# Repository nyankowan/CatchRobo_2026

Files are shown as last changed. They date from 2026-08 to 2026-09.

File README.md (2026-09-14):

# CatchRobo_2026
キャチロボ2026で使用する回路データおよび複数マイコンのプログラムを一括管理するリポジトリ.
Team: OBT

## Directory structure
```text
CatchRobo_2026/
├── common/                     ESP32/STM32が共有するプラットフォーム非依存コード
│   ├── arm/
│   │   └── アームの物理パラメータ・ホーミング関連定数・出場チーム(ROBOT_TEAM)
│   │
│   ├── can_protocol/
│   │   └── CAN IDとデータフォーマットの対応定義
│   │
│   └── coordinate/
│       └── 直交座標・極座標変換
│
├── ESP32/
│   └── controller/
│       └── Main Controller(プロコン入力の受信とCANによる各STM32への指令)
│
├── STM32/
│   ├── common/
│   │   └── can/
│   │       └── STM32 HAL CANを使ったCAN送信のラッパー
│   │
│   ├── robomas_controller/
│   │   └── 両アームのr軸・deg軸(Robomaster)制御．ホーミング処理の中枢
│   │
│   ├── lower_arm_servo/
│   │   └── 下アームのハンド(Left/Middle/Right/Expand)とShaftサーボ制御
│   │
│   ├── upper_arm_servo/
│   │   └── 上アームのShaft/Zサーボ制御
│   │
│   └── assemble_servo/
│       └── 整理機構のサーボ制御
│
└── Kicad/
    ├── ESP/
    │   └── ESP Main Controller基板
    ├── STM32F303K8_lower_arm_servo/
    │   └── サーボ制御基板(lower_arm_servo/upper_arm_servo/assemble_servoで共用)
    ├── STM32F446RE_robomas_controller/
    │   └── ロボマス制御基板
    ├── servo/
    │   └── サーボ用補助基板
    └── library/
        └── 共通シンボル・フットプリント
```

各ディレクトリの詳細は，それぞれのREADMEを参照．

| ディレクトリ | README |
| :--- | :--- |
| 共有コード | [common/README.md](common/README.md) |
| CAN通信仕様 | [common/can_protocol/README.md](common/can_protocol/README.md) |
| Main Controller | [ESP32/controller/README.md](ESP32/controller/README.md) |
| STM32全体 | [STM32/README.md](STM32/README.md) |
| 部品リスト | [Kicad/README.md](Kicad/README.md) |

## Hardware

### Actuator
- Robomaster M3508
- DS3225 Servo

### Sensor
- リミットスイッチ(ホーミング用，robomas_controllerに接続)

### Communication
- CAN 1Mbps (ESP32 - STM32, STM32 - Robomaster)

CAN ID・データフォーマットの仕様は [common/can_protocol/README.md](common/can_protocol/README.md) を参照．

## System overview

```mermaid
graph LR
    Pad1[Gamepad1] <-->|Bluetooth| ESP32[ESP32<br>中央制御]
    Pad2[Gamepad2] <-->|Bluetooth| ESP32

    ESP32 --- CAN[CAN BUS]

    CAN --- STM1[STM32 #1<br>robomas_controller]
    CAN --- STM2[STM32 #2<br>lower_arm_servo]
    CAN --- STM3[STM32 #3<br>upper_arm_servo]
    CAN --- STM4[STM32 #4<br>assemble_servo]

    STM1 <-->|CAN| Motor[Robomaster Motor<br>M3508]
    Limit[リミットスイッチ] -->|GPIO| STM1
    STM2 -->|PWM| Servo1[DS3225<br>Left/Middle/Right/Expand/Shaft]
    STM3 -->|PWM| Servo2[DS3225<br>Shaft/Z]
    STM4 -->|PWM| Servo3[DS3225<br>Assemble]
```

## Development environment

### ESP32

#### Hardware
- ESP32-DevKitC-32E

#### Software
- ESP-IDF v5.5.4
- VS Code + ESP-IDF Extension

### STM32

#### Hardware
- STM32 NUCLEO-F303K8
- STM32 NUCLEO-F446RE

#### Software
- STM32CubeMX
- CMake
- VS Code + STM32CubeIDE Extension

### KiCad

#### Software
- KiCad 10.0

## Build

### ESP32

#### Setup
[ESP-IDF環境構築手順（Windows）](https://app.notion.com/p/Windows-36e23f78736380f7b838e187b781a125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)

[ESP-IDF環境構築手順（Linux）](https://app.notion.com/p/L-32323f7873638072bacfeb84175d09c4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)

#### Build
```bash
idf.py build
```
#### Flash
```bash
idf.py flash
```

### STM32

#### Setup
[Qiita: STM32の開発をVSCodeで行う](https://qiita.com/tanutanup/items/d680c92f5168fc3f0182) [@tanutanup(tanutanu p)様](https://qiita.com/tanutanup)

#### Build
各プロジェクト(`STM32/lower_arm_servo`, `STM32/upper_arm_servo`, `STM32/robomas_controller`, `STM32/assemble_servo`)のディレクトリで実行する．
```bash
cmake --preset Release
cmake --build --preset Release
```

## 出場チーム(ROBOT_TEAM)の設定

赤/青チームはフィールドが鏡合わせで，整理機構を左右逆側に取り付けるため，DEG軸のホーミング原点やShaftサーボの回転方向をチームごとに切り替える必要がある．

出場チームは `common/arm/inc/arm.h` の `ROBOT_TEAM`(`ROBOT_TEAM_RED` / `ROBOT_TEAM_BLUE`)としてビルド時の定数で持たせている．緊急停止スイッチでESP32/STM32が再起動しても値を保持する必要があるため，実行時に切り替える方式にはしていない．

**出場チームに応じて`arm.h`のこの値を書き換えた後は，`arm.h`を使う全ファームウェア(ESP32 Main Controller，STM32の`robomas_controller` / `lower_arm_servo` / `upper_arm_servo`)を必ずビルド・書き込みし直すこと．** 値がずれると，DEG軸のホーミングで検出するリミットスイッチと回転方向が基板間で食い違い，可動域の反対側の固定端に衝突する恐れがある．

詳細は [STM32/robomas_controller/README.md](STM32/robomas_controller/README.md) を参照．

## CI

`.github/workflows/` でpush/pull request時に全ファームウェアのビルドを確認している．

| Workflow | 内容 |
| :--- | :--- |
| `esp32-build.yml` | `ESP32/controller` をESP-IDF v5.5.4でビルド |
| `stm32-build.yml` | STM32の4プロジェクトを`cmake --preset Release`でビルド |

ESP-IDFのバージョンとSTM32のツールチェーンは，上記「Development environment」およびDev Containerの設定と揃えること．

## Dev Container (Docker)

ESP-IDF拡張とSTM32系拡張は同じVS Codeウィンドウで有効になっていると干渉するため，用途別にDev Container(Docker)を分けている．必要な拡張機能だけがコンテナ内にインストールされるので，都度手動で拡張をオン/オフする必要がない．

| フォルダを開く | 使うコンテナ | 有効になる拡張 |
| :--- | :--- | :--- |
| `ESP32/controller` | `ESP32/controller/.devcontainer` | ESP-IDF |
| `STM32` | `STM32/.devcontainer` | clangd, CMake Tools, Cortex-Debug |

使い方: 対象のフォルダ(リポジトリ全体ではなく上表のフォルダ)を`File > Open Folder...`で開き，コマンドパレットから`Dev Containers: Reopen in Container`を実行する．どちらのコンテナも各プロジェクトが参照する`common/`(リポジトリ直下)を含むリポジトリ全体をマウントしたうえで，開いたフォルダをエディタ上のワークスペースフォルダとして表示する．

`STM32/.devcontainer`は`lower_arm_servo`/`upper_arm_servo`/`robomas_controller`/`assemble_servo`の4プロジェクト共通で，どのプロジェクトも同じコンテナ内でビルドできる(各プロジェクトのディレクトリに`cd`して上記の`cmake --preset`コマンドを実行)．

`ESP32/controller/.devcontainer`はコンテナ作成時に`components/procon`が依存するBluepad32/BTstack(`~/.espressif/bluepad32`)を自動で取得する(`esp32-build.yml`と同じ手順)．取得結果はDockerボリュームにキャッシュされるため，コンテナを再作成しても毎回cloneし直すことはない．

ST-Link/シリアルポート経由でのフラッシュ・デバッグにはUSBデバイスをコンテナに渡す必要があり，Linuxホスト以外(Windows/macOS)では別途パススルー設定が必要な場合がある．

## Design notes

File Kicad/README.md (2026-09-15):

# Kicad

キャチロボ2026で使用する回路データ(KiCad 10.0)と，その部品リスト．

## Directory structure

```text
Kicad/
├── ESP/
│   └── ESP Main Controller基板(ESP32-DevKitC-32E)
│
├── STM32F303K8_lower_arm_servo/
│   └── サーボ制御基板(lower_arm_servo/upper_arm_servo/assemble_servoで共用)
│
├── STM32F446RE_robomas_controller/
│   └── ロボマス制御基板(NUCLEO-F446RE)
│
├── servo/
│   └── サーボ用補助基板
│
└── library/
    └── 共通シンボル・フットプリント
```

各基板に対応するファームウェアは [STM32/README.md](../STM32/README.md) および [ESP32/controller/README.md](../ESP32/controller/README.md) を参照．

## 部品リスト

このディレクトリにあるキャチロボ2026に向けて作った回路データのほかにも，
岡ロボで使われるCANトランシーバー回路も使用している．

### 回路基板実装部品
#### マイコン基板
- lower_arm_servo基板×3（上側アームと整理機構の制御基板に流用）     
以下一つあたりの部品
    - nucleo-f303k8
    - 3φLED×1
    - 470Ω抵抗×1
    - 5ピンソケット×1
    - 6ピンソケット×1
    - 15pin socket×2

- robomas_controller基板×1
    - nucleo-f446re
    - 19*2ピンソケット×2
    - hirose 2pin(DF1EC-2P-2.5DSA(35))×7
    - 5ピンソケット×2
    - 300Ω抵抗×1
    - φ3LED×1

- ESP Main controller基板×1
    - ESP32-DevKitC-32E
    - 19ピンソケット×2
    - 2ピンソケット×2
    - 5ピンソケット×1
    - φ3LED×7
    - 470Ω抵抗×7

#### 電源基板(N先輩制作)
- catchrobo_2026電源回路×1
    - リレー(942H-2C-24DS)×1
    - ヒューズ×3
    - 470μF×3
    - xt30オス×5
    - xt30メス×4
    - φ5LED×3
    - {1200, 330}Ω抵抗×3
- catchrobo_2026分電回路×2
    - 470μF×1
    - φ5LED×1
    - {1200, 330}Ω抵抗×1
    - xt30メス×4
    - xt30オス×1

#### 補助基板
- servo基板×3   
一つあたりの部品
    - 基板取付用XT30オス(XT30PW-M)×1
    - 1kΩ抵抗×1
    - 220Ω抵抗×5
    - φ3LED×1
    - 1000μF(50PX1000MEFC12.5X25)×1
    - 0.1μF(積層セラミックコンデンサー 0.1μF100V X7R 5mmピッチ)
    - 折れ6pin hirose (DF1E-6P-2.5DS(35))×1
    - 3ピンソケット×5（ヘッダでも可）

- canトランシーバ基板ver1.b×2
- canトランシーバ基板ver1.0×1
- canトランシーバ基板ver1.0 終端抵抗なし×3

- 6.6V -> 5V DCDCコンバータ×1
    - xt30オス×1
    - xt30メス×1

### コード類
#### 電源線
- 電源供給用micro-B×3（2m級×2）
- 電源供給用micro-B×1 （もしくは 2pin オスxt30メス×1）
- 電源供給用mini-B×1　（もしくは 2pin オスxt30メス×1）
- ロボマス電源延長用 xt30 オスメス ×4（15cm程度）
- xt30延長ケーブル×∞

#### 信号線
- リミットスイッチ 2pin hirose オス×6（2m級）
- マイコン間canbus接続用2pin hirose オスオス×4（2m級）
- サーボ電源供給用 xt30オスメス×3（2m級）
- ロボマスcan延長用 2pin hirose オスメス×4（15cm程度）
- canトランシーバ接続用6pinオスメスコネクタ×1（1pin NC）

#### その他
- サーボ延長用 3pin オスメス×5

### 非常停止ボタン　動作ランプなど
- プッシュロック・ターンリセットスイッチ×1
- φ20以上緑LED×1(HWシリーズ パイロットライトΦ22(突形 LED))
- 22VLipo×3
    - xt60オス - xt30メス変換ケーブル×1
- 6.6VLipo×1(並列につなぐ場合×2)
    - xt60オス - xt30メス変換ケーブル×1

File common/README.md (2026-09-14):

# common

ESP32(Main Controller)とSTM32(各種Controller)の両方から参照される，プラットフォーム非依存のC言語共有コード．

CANの通信内容や座標変換など，複数のマイコンで同じ実装・同じ値を使う必要があるものをここに置く．
片方のマイコンでしか使わないコードはここに置かず，それぞれのプロジェクト内に置くこと．

## Directory structure

```text
common/
├── arm/
│   └── アームの物理パラメータ・ホーミング関連定数・出場チーム(ROBOT_TEAM)
│
├── can_protocol/
│   └── CAN IDとデータフォーマットの対応定義
│
└── coordinate/
    └── 直交座標(x, y) ⇔ 極座標(r, θ) の変換
```

## arm

`common/arm/inc/arm.h`

両アーム(Upper/Lower)に共通する物理パラメータと，ホーミング処理に関する定数をまとめる．

- 可動域: `*_ARM_R_RANGE`, `*_ARM_R_MIN`, `*_ARM_DEG_RANGE`, `*_ARM_DEG_MIN`
- 上アームZ軸: `UPPER_ARM_Z_MIN`, `UPPER_ARM_Z_RANGE`, `UPPER_ARM_Z_SERVO_GEAR_DIAMETER`
- 機構の諸元: `R_ROBOMAS_DIAMETER`(R軸ロボマスのギア直径), `POLAR_RATIO`(アーム軸/モーター軸の直径比)
- 出場チーム: `ROBOT_TEAM`(`ROBOT_TEAM_RED`/`ROBOT_TEAM_BLUE`)
- DEG軸のホーミング原点: `LOWER_ARM_DEG_HOME_DEG`, `UPPER_ARM_DEG_HOME_DEG`(`ROBOT_TEAM`で可動域の下限/上限どちらの端になるか変わる)
- 原点座標: `LOWER_ARM_HOME_COORDINATE`, `UPPER_ARM_HOME_COORDINATE`(同じく`ROBOT_TEAM`依存)
- ホーミングのタイムアウト・速度: `HOMING_*_ARM_TIMEOUT_MS`, `HOMING_TIMEOUT_MARGIN_RATE`, `HOMING_*_DEG_RPM`, `HOMING_*_R_RPM`(RPMはタイムアウトと可動域から自動計算される)

STM32(`robomas_controller` / `lower_arm_servo` / `upper_arm_servo`)とESP32(`arm_command.c`)が，同じ可動域・同じタイムアウト値・同じ`ROBOT_TEAM`を参照するために存在する(`assemble_servo`は`arm`を使わない)．
どれか一つだけ値を変えると，可動域チェックやタイムアウト判定，DEG軸ホーミングのリミットスイッチ・回転方向がファームウェア間でズレるので注意．特に`ROBOT_TEAM`は出場チームに応じて書き換えた後，これを使う全ファームウェアを必ずビルド・書き込みし直すこと．

## can_protocol

CAN IDとデータフォーマットの仕様．詳細は [can_protocol/README.md](can_protocol/README.md) を参照．

## coordinate

`common/coordinate/inc/coordinate.h`

```c
typedef struct { double x; double y; } direct_t; // 直交座標
typedef struct { double r; double theta; } polar_t; // 極座標 (theta: rad, 0〜2π)

polar_t to_polar(direct_t d);
```

両アームは物理的には「アームの伸び(r)」と「アームの偏角(θ)」で制御されるが，ジョイスティック入力やCAN通信上は直交座標(x, y)で扱う方が扱いやすいため，この変換関数を共有している．

## ビルドについて

各ディレクトリはそれぞれ独立したCMakeライブラリ(STM32側)／ESP-IDFコンポーネント(ESP32側)として構成されており，`add_subdirectory` または `EXTRA_COMPONENT_DIRS` 経由で各プロジェクトからリンクされる．
具体的なリンク方法は [STM32/README.md](../STM32/README.md) を参照．

| ディレクトリ | STM32でのリンク先ライブラリ名 | リンクするプロジェクト |
| :--- | :--- | :--- |
| `arm/` | `arm` | `robomas_controller`, `lower_arm_servo`, `upper_arm_servo` |
| `can_protocol/` | `can_protocol` | STM32全4プロジェクト |
| `coordinate/` | `coordinate` | `robomas_controller`, `lower_arm_servo`, `upper_arm_servo` |

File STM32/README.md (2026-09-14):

# STM32

キャチロボ2026で使用する4台のSTM32(Nucleo)のプログラムをまとめたディレクトリ．
それぞれSTM32CubeMXで生成された独立したCMakeプロジェクトであり，共通してMain Controller(ESP32)とCANで接続される．

## Directory structure

```text
STM32/
├── common/
│   └── STM32プロジェクト間の共通コード(CANラッパー等)．詳細は common/README.md 参照
│
├── robomas_controller/
│   └── 両アームのr軸・deg軸(Robomaster M3508/M2006)の制御．ホーミング処理の中枢
│
├── lower_arm_servo/
│   └── 下アームのハンド(Left/Middle/Right/Expand)とShaftサーボの制御
│
├── upper_arm_servo/
│   └── 上アームのShaft/Zサーボの制御
│
└── assemble_servo/
    └── 整理機構(Assemble)のサーボ角度制御
```

各プロジェクトの詳細は，それぞれのディレクトリ内のREADME.mdを参照．

| プロジェクト | Nucleo | 基板 | README |
| :--- | :--- | :--- | :--- |
| `robomas_controller` | NUCLEO-F446RE | `Kicad/STM32F446RE_robomas_controller` | [robomas_controller/README.md](robomas_controller/README.md) |
| `lower_arm_servo` | NUCLEO-F303K8 | `Kicad/STM32F303K8_lower_arm_servo` | [lower_arm_servo/README.md](lower_arm_servo/README.md) |
| `upper_arm_servo` | NUCLEO-F303K8 | `Kicad/STM32F303K8_lower_arm_servo`(流用) | [upper_arm_servo/README.md](upper_arm_servo/README.md) |
| `assemble_servo` | NUCLEO-F303K8 | `Kicad/STM32F303K8_lower_arm_servo`(流用) | [assemble_servo/README.md](assemble_servo/README.md) |

CAN ID・データフォーマットの仕様は [common/can_protocol/README.md](../common/can_protocol/README.md) を参照．

## ビルド

各プロジェクトのディレクトリで以下を実行する．

```bash
cmake --preset Release
cmake --build --preset Release
```

4プロジェクト共通のDev Container(`STM32/.devcontainer`)を用意しており，どのプロジェクトも同じコンテナ内でビルドできる(詳細は[リポジトリ直下のREADME.md](../README.md)を参照)．

## 共通ライブラリのリンク方法

STM32/common (CANラッパー) と，ESP32とも共有する common/ (CAN ID定義・座標変換) を，各プロジェクトの `CMakeLists.txt` から以下のようにリンクする．

### 各プロジェクトのCMakeLists.txt
```CMake
# STM32共通CAN
add_subdirectory(
    "${CMAKE_CURRENT_LIST_DIR}/../common/can"
    "${CMAKE_BINARY_DIR}/stm_can"
)

# ESP32 / STM32共通 CAN protocol
add_subdirectory(
    "${CMAKE_CURRENT_LIST_DIR}/../../common/can_protocol"
    "${CMAKE_BINARY_DIR}/can_protocol"
)

# ESP32 / STM32共通 座標処理
add_subdirectory(
    "${CMAKE_CURRENT_LIST_DIR}/../../common/coordinate"
    "${CMAKE_BINARY_DIR}/coordinate"
)

target_link_libraries(${CMAKE_PROJECT_NAME}
    stm32cubemx
    # Add user defined libraries
    stm_can
    can_protocol
    coordinate
)
```

`assemble_servo` は座標変換を使わず角度指令をそのままPWMに変換するだけなので，`coordinate` はリンクしていない(`stm_can` と `can_protocol` のみ)．

`robomas_controller` / `lower_arm_servo` / `upper_arm_servo` は，ホーミング原点・可動域・出場チーム(`ROBOT_TEAM`)の定数を使うため，上記に加えて `common/arm` も追加でリンクしている(`assemble_servo` は使わないためリンクしていない)．

```CMake
# ESP32 / STM32共通 アームパラメータ
add_subdirectory(
    "${CMAKE_CURRENT_LIST_DIR}/../../common/arm"
    "${CMAKE_BINARY_DIR}/arm"
)

target_link_libraries(${CMAKE_PROJECT_NAME}
    ...
    arm
)
```

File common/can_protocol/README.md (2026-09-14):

# CAN Communication Protocol

ESP32およびSTM32間で使用するCAN通信プロトコルの仕様を定義する．

## 1. 基本仕様

| 項目 | 仕様 |
| --- | --- |
| CAN | Classical CAN |
| Bitrate | 1 Mbps |
| CAN ID | Standard ID (11 bit) |
| 最大DLC | 8 byte |
| Byte order | Little-endian |
| CAN ID `0x000` | 使用禁止 |

CANの調停仕様により，CAN IDが小さいメッセージほど高い優先度を持つ．

複数byteの整数値はLittle-endianで格納する．

例として `int16_t value = 0x1234` の場合，

| Byte |  Value |
| ---: | -----: |
| 0 | `0x34` |
| 1 | `0x12` |

となる．

---

## 2. CAN ID一覧

|  CAN ID | Name | DLC | Description |
| ---: | --- | --: | --- |
| `0x001` | `EMERGENCY_STOP` | 0 | 緊急停止 |
| `0x005` | `ROBOMAS_CONTROLLER_HEARTBEAT` | 0 | Robomas Controller生存確認 |
| `0x006` | `UPPER_ARM_HEARTBEAT` | 0 | Upper Arm Controller生存確認 |
| `0x007` | `LOWER_ARM_HEARTBEAT` | 0 | Lower Arm Controller生存確認 |
| `0x010` | `UPPER_HOMING_ACK` | 1 | Upper Arm Homing開始確認 |
| `0x011` | `UPPER_HOMING` | 1 | Upper Arm Homing開始要求 |
| `0x015` | `UPPER_HOMING_DONE_ACK` | 1 | Upper Arm Homing完了通知の確認  |
| `0x016` | `UPPER_HOMING_DONE` | 1 | Upper Arm Homing完了通知 |
| `0x020` | `LOWER_HOMING_ACK` | 1 | Lower Arm Homing開始確認 |
| `0x021` | `LOWER_HOMING` | 1 | Lower Arm Homing開始要求 |
| `0x025` | `LOWER_HOMING_DONE_ACK` | 1 | Lower Arm Homing完了通知の確認  |
| `0x026` | `LOWER_HOMING_DONE` | 1 | Lower Arm Homing完了通知 |
| `0x100` | `UPPER_ARM_COMMAND` | 8 | Upper Armへの操作指令 |
| `0x101` | `LOWER_ARM_COMMAND` | 6 | Lower Armへの操作指令 |
| `0x102` | `ASSEMBLE_COMMAND` | 1 | Assemble機構への操作指令 |
| `0x3F0` | `ERROR_CODE` | 1 | エラー通知 |

DLCは `can_protocol_get_dlc()` によりCAN IDから決定する．

未知のCAN IDに対しては `CAN_DLC_INVALID (-1)` を返す．

---

## 3. Heartbeat

Heartbeatは各ControllerからMain Controllerへの生存確認に使用する．

Heartbeatにはデータを含めず，対応するCAN IDのフレームを受信したこと自体を生存通知として扱う．

|  CAN ID | Sender |
| ---: | --- |
| `0x005` | Robomas Controller |
| `0x006` | Upper Arm Controller |
| `0x007` | Lower Arm Controller |

DLCはすべて `0` とする．

Heartbeatの送信周期とTimeout時間は以下とする．

```c
#define HEARTBEAT_MS         300
#define HEARTBEAT_TIMEOUT_MS 1000
```

各Controllerは300 ms周期でHeartbeatを送信する．

Main Controllerが1000 ms以上Heartbeatを受信できなかった場合，そのControllerとの通信が失われたものとして扱う．

通信喪失を検出した場合は，対応するError Codeを用いてエラーとして処理する．

---

## 4. Homing

Upper ArmおよびLower ArmのHomingでは，

* Homing要求
* Homing ACK
* Homing完了通知
* Homing完了ACK

の4種類のメッセージを使用する．
ホーミング処理の中枢を担うのは`robomas_controller`のみで，
サーボ制御基板(`lower_arm_servo` / `upper_arm_servo`)はHOMINGを受け取ったときにサーボを初期位置へ戻すだけであり，
`HOMING_ACK` / `HOMING_DONE` は返さない．
`assemble_servo`はHomingに関与しない．

基本的な通信シーケンスは以下とする．

```text
Main Controller                     Robomas Controller
      |                                   |
      | -------- HOMING ----------------> |
      | <------- HOMING_ACK ------------- |
      |                                   |
      |          Homing処理                |
      |                                   |
      | <------- HOMING_DONE ------------ |
      | -------- HOMING_DONE_ACK -------->|
      |                                   |
```

Upper Armでは以下のCAN IDを使用する．

|  CAN ID | Name | Direction  |
| ---: | --- | --- |
| `0x010` | `UPPER_HOMING_ACK` | Arm → Main |
| `0x011` | `UPPER_HOMING` | Main → Arm |
| `0x015` | `UPPER_HOMING_DONE_ACK` | Main → Arm |
| `0x016` | `UPPER_HOMING_DONE` | Arm → Main |

Lower Armでは以下のCAN IDを使用する．

|  CAN ID | Name | Direction  |
| ---: | --- | --- |
| `0x020` | `LOWER_HOMING_ACK` | Arm → Main |
| `0x021` | `LOWER_HOMING` | Main → Arm |
| `0x025` | `LOWER_HOMING_DONE_ACK` | Main → Arm |
| `0x026` | `LOWER_HOMING_DONE` | Arm → Main |

すべてのHomingメッセージのDLCは `1` とする．

Byte 0にはsequence numberを格納する．

| Byte | Type | Name | Description |
| ---: | --- | --- | --- |
| 0 | `can_sequence_t` (`uint8_t`) | `sequence` | Sequence Number |

ACKには，対応する要求または通知と同じsequence numberを格納する．

例：

```text
UPPER_HOMING          : sequence = 15
UPPER_HOMING_ACK      : sequence = 15
UPPER_HOMING_DONE     : sequence = 15
UPPER_HOMING_DONE_ACK : sequence = 15
```

sequence numberは `0` ～ `255` を循環して使用する．

---

## 5. Upper Arm Command

### CAN ID

```text
0x100
```

### DLC

```text
8
```

### データフォーマット

| Byte | Type | Name | Description |
| ---: | --- | --- | --- |
|  0-1 | `int16_t` | `x` | X方向指令 (mm)  |
|  2-3 | `int16_t` | `y` | Y方向指令 (mm)  |
|  4-5 | `int16_t` | `z` | Z方向指令 (mm)  |
| 6 | `int8_t`  | `shaft_fine` | シャフト角度の微調整量(度) |
| 7 | `uint8_t` (bit 0) | `shaft_rotate` | 1:ハンドの向きを90度回転させる |

すべてLittle-endianで格納する．

```text
Byte 0 : x LSB
Byte 1 : x MSB

Byte 2 : y LSB
Byte 3 : y MSB

Byte 4 : z LSB
Byte 5 : z MSB

Byte 6 : shaft_fine

Byte 7 : shaft_rotate (bit 0のみ使用)
```

`shaft_rotate=1`は常に90度回転が適用されるとは限らない．下のアームの`shaft_rotate`(180度回転)と同様，出場チーム(青/赤)ごとに定まる，サーボの可動域内に収まるアーム偏角の範囲でのみ受信側(STM32/upper_arm_servo)が回転を適用する．

`shaft_fine`はシャフト角度の微調整オフセット(度)で，`shaft_rotate`とは独立に加算される．有効範囲は`-45`～`45`とし，送信側(`ESP32/controller/main/robot/arm_command.c`の`UPPER_ARM_SHAFT_FINE_MAX_DEG` / `LOWER_ARM_SHAFT_FINE_MAX_DEG`)でこの範囲にクランプする．

受信側の実装(座標からShaftサーボ角度への変換，クランプ)の詳細は[STM32/upper_arm_servo/README.md](../../STM32/upper_arm_servo/README.md)を参照．

C言語上では `upper_arm_t` として表現する．

```c
typedef struct {
    int16_t x;
    int16_t y;
    int16_t z;
    int8_t shaft_fine;
    uint8_t shaft_rotate : 1;
} upper_arm_t;
```

---

## 6. Lower Arm Command

### CAN ID

```text
0x101
```

### DLC

```text
6
```

### データフォーマット

| Byte | Type | Name | Description |
| ---: | --- | --- | --- |
|  0-1 | `int16_t` | `x` | X方向指令 (mm) |
|  2-3 | `int16_t` | `y` | Y方向指令 (mm) |
| 4 | `uint8_t` | `hand` | Hand操作 |
| 5 | `int8_t`  | `shaft_fine` | シャフト角度の微調整量(度) |

`hand`は各bitを以下のように使用する．left/middle/rightはそれぞれ2bitで，`hand_state_t`(0～2)の状態を表す．

| Bit | Name | Description |
| --: | --- | --- |
| 0-1 | `left` | Left hand (`hand_state_t`) |
| 2-3 | `middle` | Middle hand (`hand_state_t`) |
| 4-5 | `right` | Right hand (`hand_state_t`) |
| 6 | `expand` | Expand |
| 7 | `shaft_rotate` | 1:ハンドの向きを180度回転させる |

`shaft_rotate=1`は常に180度回転が適用されるとは限らない．出場チーム(青/赤)ごとに定まる，サーボの可動域内に収まるアーム偏角の範囲でのみ受信側(STM32/lower_arm_servo)が回転を適用する．詳細は[STM32/lower_arm_servo/README.md](../../STM32/lower_arm_servo/README.md)を参照．

`shaft_fine`はシャフト角度の微調整オフセット(度)で，`shaft_rotate`とは独立に加算される．有効範囲は`-45`～`45`とし，送信側(`ESP32/controller/main/robot/arm_command.c`の`UPPER_ARM_SHAFT_FINE_MAX_DEG` / `LOWER_ARM_SHAFT_FINE_MAX_DEG`)でこの範囲にクランプする．

`hand_state_t`は以下の3状態を取る．

| Value | Name | Description |
| ----: | --- | --- |
| 0 | `HAND_STATE_RELEASE` | ワークをリリースする状態 |
| 1 | `HAND_STATE_HOLD` | ワークを保持する状態 |
| 2 | `HAND_STATE_CATCH` | ワークをキャッチする状態  |

各状態に対応する実際のサーボ角度(パルス幅)はハンドの取り付け向きによって変わるため，プロトコルでは規定せず受信側(`lower_arm_servo`)が決める．具体的な値は[STM32/lower_arm_servo/README.md](../../STM32/lower_arm_servo/README.md)を参照．

例えば(MSBからLSBの順)，

```text
0100 0110
```

の場合，

```text
shaft_rotate = 0
expand       = 1
right        = 00 (HAND_STATE_RELEASE)
middle       = 01 (HAND_STATE_HOLD)
left         = 10 (HAND_STATE_CATCH)
```

となる．

C言語上では `lower_arm_t` として表現する．

```c
typedef enum {
    HAND_STATE_RELEASE = 0,
    HAND_STATE_HOLD    = 1,
    HAND_STATE_CATCH   = 2,
} hand_state_t;

typedef struct {
    int16_t x;
    int16_t y;
    union {
        uint8_t hand;
        struct {
            uint8_t left         : 2;
            uint8_t middle       : 2;
            uint8_t right        : 2;
            uint8_t expand       : 1;
            uint8_t shaft_rotate : 1;
        };
    };
    int8_t shaft_fine;
} lower_arm_t;
```

---

## 7. Assemble Command

### CAN ID

```text
0x102
```

### DLC

```text
1
```

Byte 0をAssemble機構への角度指令として使用する．

| Byte | Type | Name  | Description |
| ---: | --- | ----- | --- |
| 0 | `assemble_deg_t` (`uint8_t`) | `deg` | 角度指令 0～90°  |

有効範囲は `0` ～ `90` とする．この上限は `can_protocol.h` の `ASSEMBLE_DEG_RANGE`(=90) として定義し，受信側でこの値にクランプする．

受信側の実装の詳細は[STM32/assemble_servo/README.md](../../STM32/assemble_servo/README.md)を参照．

Assembleには対応するHeartbeat CAN IDが無いため，Main Controllerによる生存監視(3章)の対象外である．

---

## 8. Emergency Stop

### CAN ID

```text
0x001
```

### DLC

```text
0
```

Emergency StopはCAN通信上で最も高い優先度を持つメッセージとする．

受信したControllerは直ちに安全な状態へ移行する．

Emergency StopはCAN通信自体が失われた場合には受信できないため，Heartbeat Timeoutによる異常検出と併用する．

---

## 9. Error Code

### CAN ID

```text
0x3F0
```

### DLC

```text
1
```

Byte 0にError Codeを格納する．

| Byte | Type | Name | Description |
| ---: | --- | --- | --- |
| 0 | `can_error_t` (`uint8_t`) | `error_code` | Error Code  |

Error Codeは `can_error.h` に定義する．

現在定義されているError Codeは以下の通り．

|  Value | Name | Description |
| -----: | --- | --- |
| `0x01` | `CAN_ERROR_LOWER_R_LOST_CONTROL` | 下アームRロボマスからのフィードバックが途絶えた |
| `0x02` | `CAN_ERROR_LOWER_DEG_LOST_CONTROL`  | 下アームDEGロボマスからのフィードバックが途絶えた |
| `0x03` | `CAN_ERROR_UPPER_R_LOST_CONTROL` | 上アームRロボマスからのフィードバックが途絶えた |
| `0x04` | `CAN_ERROR_UPPER_DEG_LOST_CONTROL`  | 上アームDEGロボマスからのフィードバックが途絶えた |
| `0x10` | `CAN_ERROR_LOWER_HOMING_TIMEOUT` | 下アームのホーミングが規定時間内に完了しなかった |
| `0x11` | `CAN_ERROR_UPPER_HOMING_TIMEOUT` | 上アームのホーミングが規定時間内に完了しなかった |
| `0x20` | `CAN_ERROR_LOWER_HOMING_REJECTED` | 下アームがROBOMAS_ERROR中のためホーミング要求を無視した |
| `0x21` | `CAN_ERROR_UPPER_HOMING_REJECTED` | 上アームがROBOMAS_ERROR中のためホーミング要求を無視した |

新しいError Codeを追加する場合は，既存の値と重複しない値を `can_error.h` に追加する．

---

## 10. C言語でのデータ表現

CANデータは以下のunionで表現する．

```c
typedef union {
    uint8_t raw[CAN_DLC_MAX];

    can_sequence_t homing_sequence;
    can_error_t error_code;
    lower_arm_t lower_arm;
    upper_arm_t upper_arm;
    assemble_deg_t assemble_deg;
} can_data_t;
```

現在ESP32およびSTM32はいずれもLittle-endianであるため，CANデータと構造体のメモリ表現を共用している．

ただし，C構造体にはpaddingが挿入される可能性がある．

例えば `lower_arm_t` のCAN上のデータサイズは6 byteだが，

```c
sizeof(lower_arm_t)
```

が6 byteになることは保証されない．

したがって，CAN送信時のDLCを `sizeof()` から決定してはならない．

必ず，

```c
can_protocol_get_dlc(id)
```

によってCAN IDに対応するDLCを取得する．

各構造体が8 byteに収まること，および `can_data_t` 自体が8 byteであることは，

```c
_Static_assert(sizeof(lower_arm_t) <= CAN_DLC_MAX,
               "lower_arm_t is too large");

_Static_assert(sizeof(upper_arm_t) <= CAN_DLC_MAX,
               "upper_arm_t is too large");

_Static_assert(sizeof(can_data_t) == CAN_DLC_MAX,
               "can_data_t must be exactly 8 bytes");
```

によってコンパイル時に確認する．

---

## 11. CAN ID追加時のルール

新しいCANメッセージを追加する場合，以下を定義する．

1. CAN ID
2. メッセージ名
3. 送信元
4. 送信先
5. DLC
6. 各Byte / Bitの意味
7. データ型
8. 単位
9. 有効範囲
10. 送信周期または送信条件
11. Timeout時の処理

CAN IDを決定する際はメッセージの優先度を考慮すること．

CAN IDが小さいほどCANバス上で高い優先度を持つ．

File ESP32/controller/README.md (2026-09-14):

# ESP32/controller

Main Controller．2台のプロコン(Nintendo Switch用ジョイコン等)をBluetoothで受け取り，CAN通信で各STM32(末端マイコン)に指令を送る．

ビルド・書き込み手順とDev Containerについては[リポジトリ直下のREADME.md](../../README.md)を参照．

## Directory structure

```text
ESP32/controller/
├── .devcontainer/          ESP-IDF拡張だけを有効にしたDev Container
│
├── components/
│   ├── can/
│   │   └── CAN(TWAI)通信のラッパー
│   └── procon/
│       └── Bluetoothプロコン(Nintendo Switchコントローラー等)の接続・入力取得
│
└── main/
    ├── main.c              メインループ．プロコン入力の読み取りとロボット制御の呼び出し
    ├── gpio.h              各種GPIO番号(CAN, ステータスLED)の定義
    ├── led.c/h             ステータスLEDの初期化・点灯制御
    ├── micon_connection.c/h  各STM32のHeartbeat監視(通信生存確認)
    └── robot/
        └── arm_command.c/h   両アームへの座標指令・ホーミングシーケンスの実装
```

## components/can

CAN(TWAI)通信をサポートする．

```c
esp_err_t can_init_and_start(gpio_num_t tx, gpio_num_t rx);
esp_err_t can_tx(can_command_data_t *com);
void can_register_rx_callback(can_id_t id, can_rx_callback_t callback);
```

- `can_init_and_start()` で1MbpsのCAN通信を開始する(STM32側の設定と揃える)．
- `can_tx()` で `can_command_data_t` をtxキューに追加して送信する．
- `can_register_rx_callback()` で，特定のCAN ID(`can_id_t`)を受信した際に呼ばれるコールバックを登録できる．コールバックはCAN rx taskから直接呼ばれるため，重い処理を書かないこと．
- `can_error_handling_task()` が，CANのバスオフを検知すると自動的にリカバーする．

CAN ID・データフォーマットの仕様そのものは [common/can_protocol](../../common/can_protocol/README.md) を参照．このプロジェクトでは仕様を実装するだけで，仕様自体はここでは定義しない．

## components/procon

Bluetooth経由でプロコン(ジョイコン等)を接続し，スティック・ボタンの入力を取得する．Bluepad32/BTstackに依存しており，スタックサイズの注意点など実装上のメモは [components/procon/README.md](components/procon/README.md) を参照．

## main

### micon_connection

`CAN_ID_ROBOMAS_CONTROLLER_HEARTBEAT` / `CAN_ID_UPPER_ARM_HEARTBEAT` / `CAN_ID_LOWER_ARM_HEARTBEAT` の受信状況を監視し，各STM32との通信が生きているかを管理する．

```c
void micon_connection_init();
void micon_connection_update();      // 周期的に呼び，Heartbeatタイムアウトを判定する
bool get_connection(micon_type_t m);  // 対象のマイコンと通信できているか
```

`MICON_TYPE_ROBOMAS_CONTROLLER` / `MICON_TYPE_UPPER_ARM` / `MICON_TYPE_LOWER_ARM` の3種類とも実装済み．`assemble_servo`には対応するHeartbeat CAN IDが無いため監視対象外(詳細は[common/can_protocol/README.md](../../common/can_protocol/README.md)参照)．`micon_connection_update()`は`HEARTBEAT_TIMEOUT_MS`(1000ms)を`pdMS_TO_TICKS()`でtick単位に変換してから経過tick数と比較する(逆にすると桁を間違えるので注意)．

### robot/arm_command

両アーム(Upper/Lower)への座標指令とホーミングシーケンスを実装する．
```c
void lower_arm_move(
    int16_t dx, int16_t dy,
    bool left_pressed, bool middle_pressed, bool right_pressed,
    bool release_all_pressed,
    bool expand_toggle,
    int16_t d_shaft_fine,
    bool shaft_rotate_toggle
);
void upper_arm_move(
    int16_t dx, int16_t dy, int16_t dz,
    int16_t d_shaft_fine,
    bool shaft_rotate_toggle
);

esp_err_t send_lower_arm();
esp_err_t send_upper_arm();
esp_err_t arms_init();
esp_err_t lower_arm_homing();
esp_err_t upper_arm_homing();
void arms_update();

void lower_arm_dump();
void upper_arm_dump();
void arms_dump();
```

- `upper_arm_move()` : 座標の差分入力(dx, dy)を現在座標に加算する．可動域(`common/arm`で定義)の外に出る移動は無視する．Zは(dz)を`UPPER_ARM_Z_MIN`~`UPPER_ARM_Z_MIN + UPPER_ARM_Z_RANGE`にクランプしながら加算する．ハンドの向きは，`d_shaft_fine`(L/Rの押しっぱなしで±`UPPER_ARM_SHAFT_FINE_MAX_DEG`の範囲に収まるよう加減算する微調整量，度)と，`shaft_rotate_toggle`(ZL/ZRボタンのPRESSEDエッジ)で90度回転させる`shaft_rotate`の2段構えで制御する(下記`lower_arm_move()`のシャフト制御と同様，回転量が180度から90度になっている点のみ異なる)．ホーミング中は無視する．
- `lower_arm_move()` : 座標(dx, dy)の扱いは`upper_arm_move()`と同様．Left/Middle/Rightの各ハンドは`left_pressed`/`middle_pressed`/`right_pressed`(ボタンのPRESSEDエッジ)を受け取り，シングルクリックでHAND_STATE_CATCH↔HAND_STATE_HOLDを，ダブルクリック(`DOUBLE_CLICK_WINDOW_MS`=300ms以内の2回目の押下)でHAND_STATE_HOLD↔HAND_STATE_RELEASEをトグルする．3本ともHAND_STATE_HOLDのときに`release_all_pressed`(プラスボタン)を受け取ると3本同時にHAND_STATE_RELEASEへ切り替える(いずれかがHAND_STATE_CATCHのときは切り替わらない)．Expandは，トグル入力(ボタンのPRESSEDエッジ)で切り替える．シャフトの向きは，`d_shaft_fine`(L/Rの押しっぱなしで±`LOWER_ARM_SHAFT_FINE_MAX_DEG`の範囲に収まるよう加減算する微調整量，度)と，`shaft_rotate_toggle`(ZL/ZRボタンのPRESSEDエッジ)で180度回転させる`shaft_rotate`の2段構えで制御する．ホーミング中は座標もハンド・シャフト操作も無視する．
- `send_lower_arm()` / `send_upper_arm()` : 現在座標をCANで送信する．ホーミング中は送信しない．
- `lower_arm_homing()` / `upper_arm_homing()` : ホーミング要求(`HOMING`)をSTM32(robomas_controller)に送信する．
- `arms_update()` : 周期的に呼び，`HOMING_ACK`未受信時の要求再送(`HOMING_REQUEST_RETRY_MS`=100msごと)や，ホーミング全体のタイムアウト判定を行う．
- CAN受信コールバック(`*_homing_ack_notify`, `*_homing_done_notify`, `error_code_notify`) で，STM32側からのACK・完了通知・エラー通知を処理する．`error_code_notify`はタイムアウト系・拒否系のエラーを受け取った時点で，ESP32側の10秒待ちを待たずに即座に`homing_in_progress`を解除する．

ホーミングのシーケンス(ACK・DONE・再送を含む)の詳細は [STM32/robomas_controller/README.md](../../STM32/robomas_controller/README.md) を参照．

出場チーム(`common/arm/inc/arm.h`の`ROBOT_TEAM`)を書き換えた場合は，このファームウェアも必ずビルド・書き込みし直すこと(詳細は[リポジトリ直下のREADME.md](../../README.md)を参照)．

### led / gpio

`gpio.h`で定義された7つのLEDを`main_task`のループ毎に更新する．

| LED (`gpio.h`) | 表示内容 |
| :--- | :--- |
| `CONTROLLER_1_LED_GPIO` / `CONTROLLER_2_LED_GPIO` | 各プロコンが接続されているか |
| `ROBOMAS_CONTROLLER_STATUS_LED_GPIO` | `get_connection(MICON_TYPE_ROBOMAS_CONTROLLER)` |
| `LOWER_ARM_STATUS_LED_GPIO` | `get_connection(MICON_TYPE_LOWER_ARM)` |
| `UPPER_ARM_STATUS_LED_GPIO` | `get_connection(MICON_TYPE_UPPER_ARM)` |
| `CAN_STATUS_LED_GPIO` | `can_is_running()`(CANが`TWAI_STATE_RUNNING`か) |
| `STATUS_LED_GPIO` | `main_task`のループ毎にON/OFFを反転させる生存確認用(約3.8Hzで点滅) |

`can_is_running()`は`components/can`に追加したAPIで，`can_error_handling_task()`内で追跡している現在のTWAI状態を返す．

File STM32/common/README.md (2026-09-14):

# STM32/common

STM32側のプロジェクト(`robomas_controller`, `lower_arm_servo`, `upper_arm_servo`, `assemble_servo`)全てから共通で使われるコード．

ESP32とも共有する [common/](../../common/) (CAN ID定義・座標変換)とは別に，STM32のHALを使うコードはこちらに置く．

## Directory structure

```text
STM32/common/
└── can/
    └── STM32 HAL CANを使ったCAN送信のラッパー
```

## can

`STM32/common/can/inc/stm_can.h`

```c
HAL_StatusTypeDef stm_can_send(
    CAN_HandleTypeDef *hcan,
    const can_command_data_t *com
);
```

`common/can_protocol` で定義された `can_command_data_t` を受け取り，CAN IDから `can_protocol_get_dlc()` でDLCを決定した上で `HAL_CAN_AddTxMessage()` を呼び出す．

DLCが不正(未知のCAN IDなど)な場合は送信せず `HAL_ERROR` を返す．

受信については各プロジェクトの `HAL_CAN_RxFifo0MsgPendingCallback()` 内でそれぞれ実装しており，共通化していない．

各プロジェクトの `CMakeLists.txt` からのリンク方法は [STM32/README.md](../README.md) を参照．

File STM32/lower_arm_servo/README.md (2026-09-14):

# STM32/lower_arm_servo

下アームのハンド(Left/Middle/Right/Expand)とShaftサーボを`CAN_ID_LOWER_ARM_COMMAND`/`CAN_ID_LOWER_HOMING`(`common/can_protocol/README.md`参照)経由で制御する．

```text
                 CAN
ESP32 ──────── PA11/PA12
                   │
              STM32F303K8
                   │
       ┌───────────┴───────────┐
       │                       │
     TIM3                    TIM1
  CH1 CH2 CH3 CH4             CH1
  │    │   │   │               │
Lhand  M   R   EXP            shaft
```
## settings
### Pin

| 用途 | STM32ピン | CubeMX設定 | Nucleo端子 |
| --- | --- | --- | --- |
| Left | PB4 | TIM3_CH1 | D12 |
| Middle  | PB5 | TIM3_CH2 | D11 |
| Right | PB0 | TIM3_CH3 | D3 |
| Expand  | PB1 | TIM3_CH4 | D6 |
| Shaft | PA8 | TIM1_CH1 | D9 |
| CAN RX  | PA11 | CAN_RX | D10 |
| CAN TX  | PA12 | CAN_TX | D2 |
| STATUS_LED|PB3 |GPIO_Output| D13 |

### SYS
```text
System Core
└── SYS
Debug = Serial Wire
```
### Clock
```text
RCC
  HSI = ON

Clock Configuration

HSI = 8 MHz
   ↓
SYSCLK = 8 MHz

AHB  /1 → 8 MHz
APB1 /1 → 8 MHz
APB2 /1 → 8 MHz
```

### TIM
#### TIM1
```text
Prescaler      = 7
Counter Period = 19999
Pulse          = 1500
```
#### TIM3
```text
Prescaler      = 7
Counter Period = 19999
Counter Mode   = Up

CH1 Pulse = 1500
CH2 Pulse = 1500
CH3 Pulse = 1500
CH4 Pulse = 1500
```
### CAN
```text
Prescaler                        1
Time Quanta in Bit Segment 1     6
Time Quanta in Bit Segment 2     1
ReSynchronization Jump Width     1
```
```text
CAN
└── NVIC Settings
CAN RX0 interrupt -> Enable
```

## Code
```C
/* USER CODE BEGIN Private defines */
#define Left_htim htim3
#define Middle_htim htim3
#define Right_htim htim3
#define Expand_htim htim3
#define Shaft_htim htim1

#define Left_TIM_CHANNEL TIM_CHANNEL_1
#define Middle_TIM_CHANNEL TIM_CHANNEL_2
#define Right_TIM_CHANNEL TIM_CHANNEL_3
#define Expand_TIM_CHANNEL TIM_CHANNEL_4
#define Shaft_TIM_CHANNEL TIM_CHANNEL_1
```

```C
/* USER CODE BEGIN PD */
#define SERVO_0   500
#define SERVO_270 2500
// Left/Middle/Rightハンドの中間角度(HAND_STATE_HOLD/HAND_STATE_CATCH)のパルス幅
// SERVO_0(0度)~SERVO_270(270度)を基準に角度から線形補間する
#define SERVO_45  833
#define SERVO_225 2167

#define SERVO_150 1622
#define SERVO_120 1388

// ROBOT_TEAM(出場チーム 青/赤)はcommon/arm/inc/arm.hで定義される(ESP32/STM32の
// 全ファームウェアで共有する値なので，このファイルでは再定義しない)。
```

Left(PB4)とMiddle/Right(PB5/PB0)はサーボの取り付け向きが逆なので，同じ`hand_state_t`でも対応するパルス幅が異なる．`hand_state_to_pulse()`がどのハンドの状態かを見て以下のように振り分ける．

| `hand_state_t` | Left | Middle / Right |
| :--- | :--- | :--- |
| `HAND_STATE_RELEASE` | `SERVO_0` | `SERVO_270` |
| `HAND_STATE_HOLD` | `SERVO_45` | `SERVO_225` |
| `HAND_STATE_CATCH` | `SERVO_150` | `SERVO_120` |

Expandも同様に反転しており，`expand=1`で`SERVO_0`，`expand=0`で`SERVO_270`を出力する．

出場チーム(青/赤)は`common/arm/inc/arm.h`の`ROBOT_TEAM`をコード書き込み時に書き換えて固定する．緊急停止スイッチでESP32/STM32(robomas_controller)が再起動しても状態を保持する必要があるため，実行時にトグルする方式ではなく，ビルド時の定数として持たせている．`robomas_controller`など`arm.h`を使う全ファームウェアで必ず同じ値にすること．

### Shaftの角度計算

270度サーボのうち，Shaftが普段使うのは中央の180度(45~225度)だけである．`shaft_deg_from_arm_deg()`が，アームの可動域(`LOWER_ARM_DEG_MIN`~`LOWER_ARM_DEG_MIN + LOWER_ARM_DEG_RANGE` = 0~180度)の中央(=アームが真上向きの偏角90度)がShaft使用域の中央(135度)に一致するよう，偏角にオフセットを足すだけの単純な線形対応で目標角度を求める．

```C
static double shaft_deg_from_arm_deg(direct_t direct){
  double deg = to_polar(direct).theta / (2 * M_PI) * 360.0;
  // アーム可動域の中央(真上向き)をShaft使用域の中央(135度)に合わせるオフセット
  return deg - (LOWER_ARM_DEG_MIN + LOWER_ARM_DEG_RANGE / 2.0) + 135.0;
}
```

`LOWER_ARM_DEG_MIN`は0度で，かつ`to_polar()`の値域[0,2π)の境界と重ならないため，上アーム([STM32/upper_arm_servo/README.md](../upper_arm_servo/README.md)参照)と違い0度付近のラップ補正は不要．この対応では，赤チームのホーミング原点(`LOWER_ARM_DEG_MIN`=0度)が`SERVO_45`，青チームのホーミング原点(`LOWER_ARM_DEG_MIN + LOWER_ARM_DEG_RANGE`=180度)が`SERVO_225`になる．

`shaft_rotate=1`でハンドの向きを180度反転させると，アーム角によっては回転方向側の残り90度分の余裕を超えて可動域の反対側まで回転しきれないことがあるが，そのたびにサーボを取り替えたりはせず，後述の`clamp_servo_pulse()`でパルス幅を`SERVO_0`~`SERVO_270`にクランプすることで「それ以上は回転しない」ことをそのまま許容する．

整理機構は赤/青チームで左右逆側に取り付けるため，余裕が生まれる回転方向もチームで逆になる．`ROBOT_TEAM`に応じて，青チームは`shaft_theta`に`+M_PI`(高いパルス側の余裕を使う)，赤チームは`-M_PI`(低いパルス側の余裕を使う)を加算する．

```C
/* USER CODE BEGIN Includes */
#include "can_protocol.h"
#include "coordinate.h"
#include "stm_can.h"
#include <math.h>
```

Heartbeat送信の実装は非ブロッキング(`HAL_Delay(HEARTBEAT_MS)`のような待機はしない)．詳細は後述の[Heartbeat](#heartbeat)章を参照．

### PWM Start
```C
/* USER CODE BEGIN 2 */
HAL_TIM_PWM_Start(&htim3, Left_TIM_CHANNEL);
HAL_TIM_PWM_Start(&htim3, Middle_TIM_CHANNEL);
HAL_TIM_PWM_Start(&htim3, Right_TIM_CHANNEL);
HAL_TIM_PWM_Start(&htim3, Expand_TIM_CHANNEL);

HAL_TIM_PWM_Start(&htim1, Shaft_TIM_CHANNEL);
```
### PWM Set
以下はServo1に1.5msのPWMを設定する方法．
```C
__HAL_TIM_SET_COMPARE(
    &htim3,
    TIM_CHANNEL_1,
    1500
);
```

### CAN
```C
/* USER CODE BEGIN PV */
CAN_RxHeaderTypeDef rx_header;
can_data_t rx_data = {0};
```

`CAN_ID_LOWER_ARM_COMMAND`(x/y/Left/Middle/Right/Expand/shaft_rotate/shaft_fine)と`CAN_ID_LOWER_HOMING`を受信し，ハンドとShaftサーボのPWMを更新する．Left/Middle/Rightは`hand_state_t`(`HAND_STATE_RELEASE`/`HAND_STATE_HOLD`/`HAND_STATE_CATCH`)の3状態を取り，`hand_state_to_pulse()`で上表のパルス幅に変換する．Shaftは，`shaft_deg_from_arm_deg()`で求めた角度に対して`shaft_rotate=1`でハンドの向きを180度反転し，さらに`shaft_fine`(度)を微調整オフセットとして加えた上で，`clamp_servo_pulse()`によりパルス幅を`SERVO_0`~`SERVO_270`にクランプする．

`CAN_ID_LOWER_HOMING`受信時は`hand_fold()`でハンドをたたみ，Shaftはホーミング原点(`LOWER_ARM_HOME_COORDINATE`)に対応する向き(`shaft_home_pulse()`)にしておく．

```C
/* USER CODE BEGIN 0 */

/**
* @brief 計算したパルス幅を可動域(SERVO_0~SERVO_270)にクランプする．
*        Shaftはshaft_rotate/shaft_fineの加算で可動域を超えることがあるため，
*        クランプした分だけ回転(または微調整)が適用されないことを許容する。
*/
static uint32_t clamp_servo_pulse(double pulse){
  if(pulse < SERVO_0)return SERVO_0;
  if(pulse > SERVO_270)return SERVO_270;
  return (uint32_t)pulse;
}

/**
* @brief hand_state_t(RELEASE/HOLD/CATCH)を対応するサーボのパルス幅に変換する．
*/
static uint32_t hand_state_to_pulse(hand_state_t *state){
  if(state == NULL)return 0;
  if(state == &lower_arm_left){
    switch(*state){
      case HAND_STATE_HOLD:  return SERVO_45;
      case HAND_STATE_CATCH: return SERVO_150;
      case HAND_STATE_RELEASE:
      default:                return SERVO_0;
    }
  }else{
    switch(*state){
      case HAND_STATE_HOLD:  return SERVO_225;
      case HAND_STATE_CATCH: return SERVO_120;
      case HAND_STATE_RELEASE:
      default:                return SERVO_270;
    }
  }
}

/**
* @brief ホーミング原点(LOWER_ARM_HOME_COORDINATE，common/arm/inc/arm.h参照)に対応する
*        Shaftのパルス幅を計算する．
*/
static uint32_t shaft_home_pulse(){
  direct_t home = LOWER_ARM_HOME_COORDINATE;
  double shaft_theta = shaft_deg_from_arm_deg(home) * M_PI / 180.0;
  double shaft_pulse = shaft_theta * (SERVO_270 - SERVO_0) / (3 * M_PI_2) + SERVO_0;
  return (uint32_t)shaft_pulse;
}

/**
* @brief ハンドをたたむ(Shaftはホーミング原点の向きのままにする)
*/
static void hand_fold(){
    __HAL_TIM_SET_COMPARE(&Left_htim,Left_TIM_CHANNEL,SERVO_0);
    __HAL_TIM_SET_COMPARE(&Middle_htim,Middle_TIM_CHANNEL,SERVO_270);
    __HAL_TIM_SET_COMPARE(&Right_htim,Right_TIM_CHANNEL,SERVO_270);
    __HAL_TIM_SET_COMPARE(&Expand_htim,Expand_TIM_CHANNEL,SERVO_270);
    __HAL_TIM_SET_COMPARE(&Shaft_htim,Shaft_TIM_CHANNEL,shaft_home_pulse());
}

void HAL_CAN_RxFifo0MsgPendingCallback(CAN_HandleTypeDef *hcan){
  if(hcan->Instance != CAN)return;
  if(HAL_CAN_GetRxMessage(hcan,CAN_RX_FIFO0,&rx_header,rx_data.raw) != HAL_OK)return;

  switch (rx_header.StdId) {
  case CAN_ID_LOWER_ARM_COMMAND:
    lower_arm_left   = (hand_state_t)rx_data.lower_arm.left;
    lower_arm_middle = (hand_state_t)rx_data.lower_arm.middle;
    lower_arm_right  = (hand_state_t)rx_data.lower_arm.right;
    lower_arm_expand = rx_data.lower_arm.expand;

    __HAL_TIM_SET_COMPARE(&Left_htim,Left_TIM_CHANNEL,hand_state_to_pulse(&lower_arm_left));
    __HAL_TIM_SET_COMPARE(&Middle_htim,Middle_TIM_CHANNEL,hand_state_to_pulse(&lower_arm_middle));
    __HAL_TIM_SET_COMPARE(&Right_htim,Right_TIM_CHANNEL,hand_state_to_pulse(&lower_arm_right));
    if(rx_data.lower_arm.expand){__HAL_TIM_SET_COMPARE(&Expand_htim,Expand_TIM_CHANNEL,SERVO_0);}else{__HAL_TIM_SET_COMPARE(&Expand_htim,Expand_TIM_CHANNEL,SERVO_270);}

    direct_t direct = {.x = rx_data.lower_arm.x, .y = rx_data.lower_arm.y};
    // アームの偏角を，真上向き(90度)がShaft135度になるようオフセットした角度にする
    // (shaft_deg_from_arm_deg()参照)。
    double shaft_theta = shaft_deg_from_arm_deg(direct) * M_PI / 180.0;
    // shaft_rotate=1のとき，アーム軸の回転によらずハンドの向きを180度回転させる。
    // 270度サーボのうち普段使うのは可動範囲分の180度だけなので，回転方向側の残り90度分の
    // 余裕を超える(=可動範囲の反対側まで回転しきれない)場合は，下のclamp_servo_pulse()で
    // パルス幅がクランプされ，それ以上は回転しない(毎回サーボを取り替える運用はしない)。
    // 整理機構は赤/青チームで左右逆側に取り付けるため(arm.h参照)，余裕が生まれる側(=回転
    // させる方向)もチームで逆になる。青は+M_PI(高いパルス側に余裕)，赤は-M_PI(低いパルス側に
    // 余裕)とする。
#if ROBOT_TEAM == ROBOT_TEAM_BLUE
    if(rx_data.lower_arm.shaft_rotate){shaft_theta += M_PI;}
#else
    if(rx_data.lower_arm.shaft_rotate){shaft_theta -= M_PI;}
#endif
    // シャフト角度の微調整(度)。L/Rの押しっぱなしでESP32側が加減算した値をそのまま加える
    shaft_theta += rx_data.lower_arm.shaft_fine * M_PI / 180.0;
    double shaft_pulse = shaft_theta * (SERVO_270 - SERVO_0) / (3 * M_PI_2) + SERVO_0;
    __HAL_TIM_SET_COMPARE(&Shaft_htim,Shaft_TIM_CHANNEL,clamp_servo_pulse(shaft_pulse));
    break;

  case CAN_ID_LOWER_HOMING:
    lower_arm_left = HAND_STATE_RELEASE;
    lower_arm_middle = HAND_STATE_RELEASE;
    lower_arm_right = HAND_STATE_RELEASE;
    lower_arm_expand = false;

    hand_fold();
    break;

  default:
    break;
  }
}
```
```C
/* USER CODE BEGIN 2 */
HAL_CAN_Start(&hcan);
if (HAL_CAN_ActivateNotification(&hcan,CAN_IT_RX_FIFO0_MSG_PENDING) != HAL_OK) {
  Error_Handler();
}
```

### Heartbeat

mainループ内で`HEARTBEAT_MS`(300ms，`common/can_protocol`で定義)周期ごとに`CAN_ID_LOWER_ARM_HEARTBEAT`を送信する．ESP32側はこれの受信有無でLower Arm Controllerとの通信生存を判定する(詳細は[common/can_protocol/README.md](../../common/can_protocol/README.md)のHeartbeat章参照)．

```C
/* USER CODE BEGIN WHILE */
uint32_t last_heartbeat = HAL_GetTick();
while (1)
{
  status_led_update();

  if(HAL_GetTick() - last_heartbeat > HEARTBEAT_MS){
    last_heartbeat = HAL_GetTick();
    stm_can_send(&hcan, &(can_command_data_t){.id = CAN_ID_LOWER_ARM_HEARTBEAT});
  }
  /* USER CODE END WHILE */
  HAL_Delay(LOOP_MS);
  /* USER CODE BEGIN 3 */
}
```

```C
/* USER CODE BEGIN CAN_Init 2 */
/* can_rx setting */
CAN_FilterTypeDef filter;

filter.FilterBank = 0;
filter.FilterMode = CAN_FILTERMODE_IDMASK;
filter.FilterScale = CAN_FILTERSCALE_32BIT;

/* 受信IDフィルター　全受信 */
filter.FilterIdHigh = 0x0000;
filter.FilterIdLow = 0x0000;
filter.FilterMaskIdHigh = 0x0000;
filter.FilterMaskIdLow = 0x0000;

filter.FilterFIFOAssignment = CAN_RX_FIFO0; //fifo(first-in first-out) = Queue
filter.FilterActivation = ENABLE;

if (HAL_CAN_ConfigFilter(&hcan, &filter) != HAL_OK) {
    Error_Handler();
}
/* can_rx setting */
```

### LED

Status_LEDは，Left/Middle/Right/Expandそれぞれの現在の状態(true=ON)を点滅回数で表示する．Left/Middle/Rightは`hand_state_t`のHAND_STATE_RELEASE以外(HOLD/CATCH)をONとして扱う．CAN受信ハンドラでON/OFFを保持しておき，`status_led_update()`を周期的(mainループ毎)に呼ぶことで非ブロッキングに表示する．

表示順は Left → Middle → Right → Expand で，各chはONなら2回，OFFなら1回の短い点滅で表す(点滅回数を数えればON/OFFが分かる)．周期の始まりは長い点灯(マーカー)で示す．

```text
[長い点灯(マーカー)] [消灯] [Left:1or2回点滅] [消灯] [Middle:1or2回点滅] [消灯] [Right:...] [消灯] [Expand:...] [消灯(長め)] → 最初に戻る
```

| 定数 | 値 | 説明 |
| :--- | ---: | :--- |
| `STATUS_LED_MARKER_MS` | 1000 ms | 周期の始まりを示す長い点灯 |
| `STATUS_LED_BLINK_MS` | 100 ms | 1回分の点滅の点灯時間 |
| `STATUS_LED_INTRA_GAP_MS` | 100 ms | ONの2回点滅の間の消灯時間 |
| `STATUS_LED_CHANNEL_GAP_MS` | 700 ms | ch同士の間，およびマーカー直後の消灯時間 |
| `STATUS_LED_END_PAUSE_MS` | 1200 ms | 4ch分表示し終えてから次のマーカーまでの消灯時間 |

実装は`status_led_state_t`によるステートマシン(`STATUS_LED_STATE_MARKER` → `..._CHANNEL_GAP` → `..._BLINK_ON`/`..._BLINK_GAP`(chごとに1〜2回) → `..._END_PAUSE` → 最初に戻る)．ONかOFFかで点滅回数が変わるため，固定長のフェーズ表ではなくこの状態機械で管理している．

`CAN_ID_LOWER_HOMING`受信時は4chとも状態をOFFにリセットし，`hand_fold()`で実際にサーボもたたんだ位置へ戻す．Shaftサーボは，たたんだ状態にはせずホーミング原点(`LOWER_ARM_HOME_COORDINATE`)に対応する向き(`shaft_home_pulse()`)に戻す(ホーミング開始時点からホーミング完了時と同じ向きにしておくことで，完了時にハンドの向きが変わらないようにするため)．Shaftの状態はStatus_LEDの点滅表示には含まれない．

```C
/* USER CODE BEGIN 2 */
HAL_GPIO_WritePin(
  STATUS_LED_GPIO_Port,
  STATUS_LED_Pin,
  GPIO_PIN_SET
);
```
```C
// 点灯
HAL_GPIO_WritePin(
    STATUS_LED_GPIO_Port,
    STATUS_LED_Pin,
    GPIO_PIN_SET
);

// 消灯
HAL_GPIO_WritePin(
    STATUS_LED_GPIO_Port,
    STATUS_LED_Pin,
    GPIO_PIN_RESET
);

// 反転
HAL_GPIO_TogglePin(
    STATUS_LED_GPIO_Port,
    STATUS_LED_Pin
);
```

### Error_Handler
```C
/* USER CODE BEGIN Error_Handler_Debug */
/* User can add his own implementation to report the HAL error return state */
__disable_irq();
while (1)
{
  HAL_GPIO_TogglePin(
  STATUS_LED_GPIO_Port,
  STATUS_LED_Pin
  );
  HAL_Delay(1000);
}
```

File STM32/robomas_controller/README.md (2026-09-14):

# STM32/robomas_controller

両アームのアーム長(r軸)とアーム偏角(deg軸)をRobomaster(M3508/M2006)により制御する．ホーミング処理の中枢を担う．

## settings
### Pin

| 用途 | STM32ピン | CubeMX設定 |
| :--- | :--- | :--- |
| CAN1 (Main Controllerとの通信) | PA11/PA12 | COMMAND_CAN_RX/TX |
| CAN2 (Robomasterとの通信) | PB12/PB13 | ROBOMAS_CAN_RX/TX |
| Status_LED | PA5 | GPIO_Output |
| Upper Arm R軸 リミットスイッチ | PC2 | GPIO_Input (UPPER_ARM_R_LIMIT) |
| Upper Arm Deg軸 下限リミットスイッチ | PC3 | GPIO_Input (UPPER_ARM_DEG_UNDER_LIMIT) |
| Upper Arm Deg軸 上限リミットスイッチ | PC4 | GPIO_Input (UPPER_ARM_DEG_OVER_LIMIT) |
| Lower Arm R軸 リミットスイッチ | PC5 | GPIO_Input (LOWER_ARM_R_LIMIT) |
| Lower Arm Deg軸 下限リミットスイッチ | PC10 | GPIO_Input (LOWER_ARM_DEG_UNDER_LIMIT) |
| Lower Arm Deg軸 上限リミットスイッチ | PC11 | GPIO_Input (LOWER_ARM_DEG_OVER_LIMIT) |

DEG軸は`ROBOT_TEAM`(下記「DEG軸のホーミング方向とROBOT_TEAM」参照)に応じて`_UNDER_LIMIT`/`_OVER_LIMIT`のどちらか一方をホーミングに使う．R軸は`_R_LIMIT`のみ(チームに依らず固定)．

### CAN

他プロジェクト(NUCLEO-F303K8)と違いNUCLEO-F446REのためCubeMXの設定値が異なるが，ビットレートは同じ1Mbps．

| | CAN1 (Main Controller) | CAN2 (Robomaster) |
| :--- | :--- | :--- |
| Prescaler | 2 | 2 |
| Time Quanta in Bit Segment 1 | 12 | 12 |
| Time Quanta in Bit Segment 2 | 2 | 2 |

## 概要

すべてのロボマスターからフィードバックを正常に受け取ることができてから，    
Main Controllerからホーミング指令を受け取り，ホーミング処理が完了して初めて，Main Controllerから制御可能になる．    
ホーミング処理中はMain Controllerからの指令を無視する． 
ホーミング処理はアームごと(r軸・deg軸の2ロボマス1組)に行う．

CAN上のメッセージフォーマットやCAN IDの詳細は [common/can_protocol/README.md](../../common/can_protocol/README.md) を参照．
このREADMEでは，robomas_controller自身がその仕様をどう実装しているか(状態遷移・タイムアウト・再送)を説明する．

サーボ制御基板(`lower_arm_servo` / `upper_arm_servo`)は`HOMING`を受け取ったときにサーボを初期位置へ戻すだけで，`HOMING_ACK` / `HOMING_DONE` は返さない．

mainループ内では`HEARTBEAT_MS`(300ms)周期で`CAN_ID_ROBOMAS_CONTROLLER_HEARTBEAT`を送信し，Main Controllerとの通信生存を通知する(他のSTM32と共通の仕組み)．

## ROBOMASTER_STATE
```C
typedef enum{
  ROBOMAS_INITIAL,  // 初回起動時状態
  ROBOMAS_HOMING,   // 速度制御によって，リミットスイッチ位置まで回転する
  ROBOMAS_IDLE,     // ホーミング終了による他のホーミングを待機
  ROBOMAS_READY,    // ユーザが制御可能な状態
  ROBOMAS_ERROR,    // ロボマスからのフィードバックが途絶えた異常状態
}robomas_state_t;
```
| Value |  explanation |
| :--- | :--- |
|`ROBOMAS_INITIAL`  | マイコン起動時の初期状態．Main Controllerからのホーミング指令により `ROBOMAS_HOMING` に遷移する．|
|`ROBOMAS_HOMING` | ホーミング処理中の状態．リミットスイッチからの信号で `ROBOMAS_IDLE` に遷移する．規定時間内に遷移しなければタイムアウトし `ROBOMAS_INITIAL` に戻る．|
|`ROBOMAS_IDLE` | ホーミング処理を終了し，もう片方(r軸/deg軸)のホーミング完了待ち．両ロボマスがこの状態になると同時に`ROBOMAS_READY`に遷移する．|
|`ROBOMAS_READY` | Main Controllerからの座標指令をもとに制御を行える状態．ホーミング指令により `ROBOMAS_HOMING` に遷移する．|
|`ROBOMAS_ERROR` | `ROBOMAS_FEEDBACK_TIMEOUT_MS`(100ms)以上ロボマスからのフィードバックを受信できていない状態．トルク出力は強制的に0にする．フィードバックが復帰すると自動的に`ROBOMAS_INITIAL`に戻る(制御を再開するには再度ホーミングが必要)．|

r軸・deg軸は基本的に独立して状態遷移するが，`ROBOMAS_READY`への遷移(ホーミング完了)だけは両方が`ROBOMAS_IDLE`になった瞬間に同時に行われる．

---

## ロボマスターのCAN ID対応

`robomas_receive()`は受信したCAN ID(0x201〜0x204)をそのまま配列indexに変換して`robomas[]`に格納している．

```c
uint8_t robomas_id = rx_header.StdId - 0x201; // 0x201→0, 0x202→1, 0x203→2, 0x204→3
```

このindexと実際のアーム・軸の対応は以下の通り．**ロボマスター(C620等)側のCAN ID設定は，この対応に合わせて配線・設定すること．**

| CAN ID | `robomas[]` index | マクロ名 | 対応する軸 |
| :---: | :---: | :--- | :--- |
| `0x201` (ID1) | `robomas[0]` | `robomas_lower_deg` | 下アーム 偏角(deg) |
| `0x202` (ID2) | `robomas[1]` | `robomas_lower_r` | 下アーム 伸縮(r) |
| `0x203` (ID3) | `robomas[2]` | `robomas_upper_deg` | 上アーム 偏角(deg) |
| `0x204` (ID4) | `robomas[3]` | `robomas_upper_r` | 上アーム 伸縮(r) |

配線側のCAN ID設定とこの対応がずれると，例えば意図したR軸の代わりにDEG軸のエラーが報告される，といった混乱の原因になるので注意．

---

## Homingシーケンス

`common/can_protocol/README.md` に記載の

```text
Main Controller                     Robomas Controller
      |                                   |
      | -------- HOMING ----------------> |
      | <------- HOMING_ACK ------------- |
      |                                   |
      |          Homing処理                |
      |                                   |
      | <------- HOMING_DONE ------------ |
      | -------- HOMING_DONE_ACK -------->|
      |                                   |
```

を，CANフレーム欠落があっても最終的に完了できるよう，双方向に再送を実装している．

### HOMING受信 → HOMING_ACK送信
- `CAN_ID_UPPER_HOMING` / `CAN_ID_LOWER_HOMING` を受信すると，受信したsequence numberを保持し，即座に同じsequence numberで `HOMING_ACK` を返す．
- Main Controller側は `HOMING_ACK` が `HOMING_REQUEST_RETRY_MS`(100ms) 以内に届かなければ同じsequence numberでHOMING要求を再送する(実装は`ESP32/controller/main/robot/arm_command.c`)．
- 該当軸が既に`ROBOMAS_IDLE`(もう片方のホーミング待ち)の場合，sequence numberが今処理中のものと一致すればACK消失による再送とみなしてACKを返し直す．一致しない場合は新規の要求とみなし無視する．
- 該当軸が`ROBOMAS_ERROR`の場合，ホーミングは開始せず，`CAN_ID_ERROR_CODE`(`CAN_ERROR_*_HOMING_REJECTED`)を返す．

### Homing処理
- `HOMING_UPPER_DEG_RPM` / `HOMING_LOWER_DEG_RPM` / `HOMING_UPPER_R_RPM` / `HOMING_LOWER_R_RPM` (`common/arm/inc/arm.h`)で指定される回転数でリミットスイッチ方向へ回転する．
- リミットスイッチ検出で`ROBOMAS_IDLE`に遷移し，その時点のロボマス角度を極座標原点として記録する．r軸は`*_ARM_R_MIN`，deg軸は`LOWER/UPPER_ARM_DEG_HOME_DEG`(`common/arm/inc/arm.h`。チーム・原点にする可動端で変わる。下記参照)を考慮したオフセット付き．
- `HOMING_UPPER_ARM_TIMEOUT_MS` / `HOMING_LOWER_ARM_TIMEOUT_MS`(いずれも10000ms)以内にリミットスイッチを検出できなければ，両軸を`ROBOMAS_INITIAL`に戻し，`CAN_ID_ERROR_CODE`(`CAN_ERROR_*_HOMING_TIMEOUT`)を送信する．リミットスイッチ故障や配線不良で無限に回転し続けることを防ぐための仕組み．
- このタイムアウト通知は，一度のホーミング試行につき`upper/lower_homing_timeout_notified`フラグにより1回だけ送信される．`ROBOMAS_ERROR`(フィードバック途絶)状態の軸は上書きせずそのまま`robomas_update()`に管理を委ねるため，タイムアウト処理と`ROBOMAS_ERROR`検知が互いの状態を打ち消し合って`CAN_ID_ERROR_CODE`を送り続ける(スパムする)ことがない．フラグは新しいホーミング要求を受理した時点でリセットされる．

### DEG軸のホーミング方向とROBOT_TEAM
赤/青チームはフィールドが鏡合わせのため，整理機構を左右逆側に付け替える必要がある(機体自体は鏡像に反転するのではなく，180度回転させて取り付ける)．これに合わせて，上下アームとも「DEG軸(偏角)のどちら側の可動端(リミットスイッチ)をホーミング原点にするか」をチームで切り替える．

- 赤チーム: 可動域下限側(`*_DEG_UNDER_LIMIT`，整理機構は左)を原点にする(従来通り)．
- 青チーム: 可動域上限側(`*_DEG_OVER_LIMIT`，整理機構は右)を原点にする．

`ROBOT_TEAM`(`ROBOT_TEAM_RED`/`ROBOT_TEAM_BLUE`)は`common/arm/inc/arm.h`で定義され，ESP32 Main Controller・`lower_arm_servo`・`upper_arm_servo`とこのファームウェアで共有する．**出場チームに応じて`arm.h`のこの値を書き換えてから，全ファームウェアをビルド・書き込みすること(値がずれると，DEG軸のホーミングで検出するリミットスイッチと回転方向が基板間で食い違い，可動域の反対側の固定端に衝突する恐れがある)．**

このファームウェア内では，`ROBOT_TEAM`に応じて以下を切り替えている:
- `*_DEG_HOMING_LIMIT_ON`: ホーミング完了を検出するリミットスイッチ(`*_DEG_UNDER_LIMIT_ON`/`*_DEG_OVER_LIMIT_ON`)．
- `*_DEG_HOMING_DIRECTION_SIGN`: ホーミング時の回転方向の符号．原点にする側へ実際に向かうよう反転させる(配線・機構で決まる固定値`*_DEG_ROBOMAS_DIRECTION`自体は変えない)．
- `set_robomas_deg_from_coordinate()`内の`polar_deg_unwrapped()`: 偏角が360度(=0度)をまたぐ場合(青チームでの上アーム等)に，`to_polar()`の値域[0,2π)によるラップで原点付近の値が不連続にならないよう正規化する．

R軸(アームの伸縮，並進)は原点にする可動端が変わらないため，チームに依らず固定．

### HOMING_DONE送信 → HOMING_DONE_ACK待ち
- 両軸が`ROBOMAS_IDLE`になった瞬間，`ROBOMAS_READY`に遷移すると同時に，保持していたsequence numberで`HOMING_DONE`を送信する．
- `HOMING_DONE_ACK_RETRY_MS`(200ms)ごとに`HOMING_DONE_ACK`の到着を確認し，届いていなければ`HOMING_DONE`を再送する．最大`HOMING_DONE_ACK_MAX_RETRY`(5回)まで再送し，それでも届かなければ諦める(この場合もアーム自体は`ROBOMAS_READY`のまま動作可能)．

---

## 異常検知とエラー通知 (`CAN_ID_ERROR_CODE`)

以下のタイミングで`CAN_ID_ERROR_CODE`(詳細は`common/can_protocol/README.md`)を送信する．

| タイミング | 送信するError Code |
| :--- | :--- |
| ロボマスからのフィードバックが途絶え`ROBOMAS_ERROR`に遷移した瞬間 | `CAN_ERROR_{LOWER,UPPER}_{R,DEG}_LOST_CONTROL` |
| ホーミングが`HOMING_*_ARM_TIMEOUT_MS`以内に完了しなかった | `CAN_ERROR_{LOWER,UPPER}_HOMING_TIMEOUT` |
| `ROBOMAS_ERROR`中にホーミング要求を受けて無視した | `CAN_ERROR_{LOWER,UPPER}_HOMING_REJECTED` |

いずれも状態遷移の瞬間に1回だけ送信し，同じ状態が続く間は再送しない(CANバスを埋めないため)．

---

## 主要タイミング定数一覧

| 定数 | 値 | 定義箇所 | 説明 |
| :--- | ---: | :--- | :--- |
| `ROBOMAS_FEEDBACK_TIMEOUT_MS` | 100 ms | `robomas_controller/Core/Src/main.c` | この時間フィードバックが無いと`ROBOMAS_ERROR`へ |
| `HOMING_UPPER_ARM_TIMEOUT_MS` / `HOMING_LOWER_ARM_TIMEOUT_MS` | 10000 ms | `common/arm/inc/arm.h` | ホーミング全体のタイムアウト．ESP32側の待ち時間も同じ値を参照する |
| `HOMING_DONE_ACK_RETRY_MS` | 200 ms | `robomas_controller/Core/Src/main.c` | `HOMING_DONE`の再送間隔 |
| `HOMING_DONE_ACK_MAX_RETRY` | 5 回 | `robomas_controller/Core/Src/main.c` | `HOMING_DONE`の最大再送回数 |
| `HOMING_REQUEST_RETRY_MS` | 100 ms | `ESP32/controller/main/robot/arm_command.c` | `HOMING`要求(Main Controller→Arm)の再送間隔 |

`HOMING_UPPER/LOWER_DEG_RPM`・`HOMING_UPPER/LOWER_R_RPM`は，上記タイムアウトに対して`HOMING_TIMEOUT_MARGIN_RATE`分の余裕(既定60%)を持って完了するよう`common/arm/inc/arm.h`で自動計算している．

---

## Status_LED

`status_led_update()`が，lower/upperそれぞれのアームが`ROBOMAS_READY`(r軸・deg軸とも)かどうかをStatus_LEDの点滅回数で表示する．周期的(mainループ毎)に呼び出す非ブロッキングの実装．

| 状態 | 表示 |
| :--- | :--- |
| 両方`READY` | 常時点灯 |
| lowerのみ未`READY` | 1回点滅 |
| upperのみ未`READY` | 2回点滅 |
| 両方とも未`READY` | 3回点滅 |

点滅回数 = (lowerが未READYなら+1) + (upperが未READYなら+2) で算出しており，1回点滅→短い消灯→1回点滅…を`blink_count`回繰り返した後，`STATUS_LED_BLINK_PAUSE_MS`(700ms)の消灯を挟んで最初から繰り返す．

| 定数 | 値 | 説明 |
| :--- | ---: | :--- |
| `STATUS_LED_BLINK_ON_MS` | 150 ms | 1回の点滅の点灯時間 |
| `STATUS_LED_BLINK_OFF_MS` | 150 ms | 点滅同士の間の消灯時間 |
| `STATUS_LED_BLINK_PAUSE_MS` | 700 ms | 1周(blink_count回)表示し終えた後の消灯時間 |

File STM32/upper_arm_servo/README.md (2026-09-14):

# STM32/upper_arm_servo

上アームのShaft(ハンドの向き)とZ(昇降)サーボを`CAN_ID_UPPER_ARM_COMMAND`/`CAN_ID_UPPER_HOMING`(`common/can_protocol/README.md`参照)経由で制御する．

同じ回路基板(NUCLEO-F303K8，`Kicad/STM32F303K8_lower_arm_servo`)を使う[STM32/lower_arm_servo](../lower_arm_servo/README.md)と，ピン・タイマー設定・CAN送受信・Status_LEDの基本パターンは共通．CubeMXの詳細な設定値はそちらのREADMEを参照．

## settings
### Pin

| 用途 | STM32ピン | CubeMX設定 | Nucleo端子 |
| --- | --- | --- | --- |
| Shaft | PA8 | TIM1_CH1 | D9 |
| Z | PB1 | TIM3_CH4 | D6 |
| CAN RX  | PA11 | CAN_RX | D10 |
| CAN TX  | PA12 | CAN_TX | D2 |
| STATUS_LED | PB3  | GPIO_Output | D13 |

### TIM

TIM1(Shaft)/TIM3(Z)とも，PWM 20ms周期．`lower_arm_servo`と同じ`Prescaler=7`, `Counter Period=19999`．

### CAN

Prescaler=1, BS1=6TQ, BS2=1TQ, SJW=1TQ (他のF303K8プロジェクトと共通，1Mbps)．

## Code

```C
/* USER CODE BEGIN Private defines */
#define Shaft_htim htim1
#define Z_htim htim3

#define Shaft_TIM_CHANNEL TIM_CHANNEL_1
#define Z_TIM_CHANNEL TIM_CHANNEL_4
```

```C
/* USER CODE BEGIN PD */
#define SERVO_0   500
#define SERVO_270 2500

#define LOOP_MS 2

// 受信コマンドが可動域外でクランプされた場合は高速点滅に切り替えてエラーを知らせる
#define STATUS_LED_ERROR_BLINK_MS 100
```

## 実装状況

`CAN_ID_UPPER_ARM_COMMAND`を受信し，x/yから求めたアームの偏角をShaftサーボ，zをZサーボのPWMへ反映する．`CAN_ID_UPPER_HOMING`受信時はShaftのみホーミング原点(`UPPER_ARM_HOME_COORDINATE`)の向き(`shaft_home_pulse()`)へ戻す(Zは現在位置を維持する)．ホーミング開始時点からホーミング完了時と同じ向きにしておくことで，完了時にハンドの向きが変わらないようにしている(下アームの`shaft_home_pulse()`と同じ考え方，[STM32/lower_arm_servo/README.md](../lower_arm_servo/README.md)参照)．

Homing処理そのもの(リミットスイッチ検出・ロボマスの制御)は`robomas_controller`が担当し，このファームウェアは`HOMING_ACK`/`HOMING_DONE`を返さない(詳細は[common/can_protocol/README.md](../../common/can_protocol/README.md)の4章)．

### Shaftの角度計算

上のアームはハンドの取り付け側が下のアームと逆(180度回転してついている)ため，偏角の可動域は`UPPER_ARM_DEG_MIN`~`UPPER_ARM_DEG_MIN + UPPER_ARM_DEG_RANGE`(180~360度)になる(`common/arm/inc/arm.h`参照)．

Shaftは可動範囲270度のうち中央の180度(45~225度)だけを通常使用域とし，`shaft_deg_from_arm_deg()`が，アームの可動域の中央(=アームが真下向きの位置)がShaft使用域の中央(135度)に一致するよう，偏角からオフセットを引くだけの単純な線形対応で目標角度を求める．

```C
static double shaft_deg_from_arm_deg(direct_t direct){
  double deg = to_polar(direct).theta / (2 * M_PI) * 360.0;
  if(deg < UPPER_ARM_DEG_MIN) deg += 360.0;
  // アーム可動域の中央(真下向き)をShaft使用域の中央(135度)に合わせるオフセット
  return deg - (UPPER_ARM_DEG_MIN + UPPER_ARM_DEG_RANGE / 2.0) + 135.0;
}
```

`fabs()`等で折り返さない線形対応にすることで，アームの回転方向とShaftの回転方向が常に一致し，かつ計算式自体はチームによらず共通になる．チーム差は`UPPER_ARM_HOME_COORDINATE`(`common/arm/inc/arm.h`)が可動域のどちら側の座標になるかにのみ現れ，赤チームのホーミング原点(`UPPER_ARM_DEG_MIN`=180度)では`SERVO_45`，青チームのホーミング原点(`UPPER_ARM_DEG_MIN + UPPER_ARM_DEG_RANGE`=360度)では`SERVO_225`になる．

360度は`coordinate.h`の`to_polar()`の値域[0,2π)では0度としてラップされるため，偏角が0度付近で不連続にならないよう，`UPPER_ARM_DEG_MIN`未満の値には360度を足してから使う．

`shaft_deg_from_arm_deg()`で求めた角度には，さらに`shaft_rotate`(1のときハンドの向きを90度回転させる)と`shaft_fine`(度単位の微調整オフセット)を加算してからShaftサーボのパルス幅に変換する．下のアーム([STM32/lower_arm_servo/README.md](../lower_arm_servo/README.md)参照)と同じ考え方で，270度サーボのうち通常使うのは可動範囲分の180度だけなので，`shaft_rotate=1`による90度回転が残り90度分の余裕を超える場合は下記のクランプにより「それ以上は回転しない」ことを許容する．余裕が生まれる回転方向は整理機構の取り付け側に応じてチームで逆になるため，`ROBOT_TEAM`に応じて青チームは`+90`度，赤チームは`-90`度を加算する．`shaft_fine`は`shaft_rotate`とは独立に加算し，有効範囲は`-45`～`45`度とする(`ESP32/controller/main/robot/arm_command.c`の`UPPER_ARM_SHAFT_FINE_MAX_DEG`)．

### Zの角度計算

zは`UPPER_ARM_Z_SERVO_GEAR_DIAMETER`(`common/arm/inc/arm.h`)のギアで昇降量(mm)からサーボ角度に換算する．

```C
double z_pulse = rx_data.upper_arm.z * (SERVO_270 - SERVO_0) / (UPPER_ARM_Z_SERVO_GEAR_DIAMETER * 3 * M_PI_4) + SERVO_0;
```

### Status_LED

Shaft/Zとも，計算したパルス幅を`SERVO_0`~`SERVO_270`の範囲にクランプしてから`__HAL_TIM_SET_COMPARE()`する．クランプが発生した(=可動域外のコマンドを受信した，または上記の`shaft_rotate`/`shaft_fine`加算で可動域を超えた)場合はSTATUS_LEDを高速点滅(`STATUS_LED_ERROR_BLINK_MS`=100ms)させてエラーを知らせる．正常時はSTATUS_LEDを点灯させ，動作中であることを示す(いずれも`status_led_update()`をmainループ毎に呼ぶことで非ブロッキングに実現)．

なお，ESP32側(`ESP32/controller/main/robot/arm_command.c`)でも送信前にx/y/zを可動域(`common/arm/inc/arm.h`の`UPPER_ARM_R_RANGE`/`UPPER_ARM_DEG_RANGE`/`UPPER_ARM_Z_RANGE`)にクランプしているため，STM32側のクランプは想定外の入力に対する保険(二重の安全策)という位置づけ．

### Heartbeat

mainループ内で`HEARTBEAT_MS`(300ms，`common/can_protocol`で定義)周期ごとに`CAN_ID_UPPER_ARM_HEARTBEAT`を送信する．ESP32側はこれの受信有無でUpper Arm Controllerとの通信生存を判定する(詳細は[common/can_protocol/README.md](../../common/can_protocol/README.md)のHeartbeat章参照)．

```C
/* USER CODE BEGIN WHILE */
uint32_t last_heartbeat = HAL_GetTick();
while (1)
{
  status_led_update();

  if(HAL_GetTick() - last_heartbeat > HEARTBEAT_MS){
    last_heartbeat = HAL_GetTick();
    stm_can_send(&hcan, &(can_command_data_t){.id = CAN_ID_UPPER_ARM_HEARTBEAT});
  }
  /* USER CODE END WHILE */

  HAL_Delay(LOOP_MS);
  /* USER CODE BEGIN 3 */
}
```

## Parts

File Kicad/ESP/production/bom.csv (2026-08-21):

Designator | Footprint | Quantity | Value | LCSC Part #
D1 | LED_D3.0mm | 1 | CAN_STATUS
D2 | LED_D3.0mm | 1 | LOW_STATUS
D3 | LED_D3.0mm | 1 | UP_STATUS
D4 | LED_D3.0mm | 1 | RBMAS_S
D5 | LED_D3.0mm | 1 | CON_1
D6 | LED_D3.0mm | 1 | CON_2
D7 | LED_D3.0mm | 1 | STATUS
J1 | PinHeader_1x02_P2.54mm_Vertical | 1 | 5V
J2 | PinHeader_1x05_P2.54mm_Vertical | 1 | CAN
J3 | PinHeader_1x02_P2.54mm_Vertical | 1 | 3V3
R1, R2, R3, R4, R5, R6, R7 | R_Axial_DIN0207_L6.3mm_D2.5mm_P7.62mm_Horizontal | 7 | 300R
U1 | ESP32_DevKitC_32E | 1 | ESP32_DevKitC-32E

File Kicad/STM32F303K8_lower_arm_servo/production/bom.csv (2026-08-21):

Designator | Footprint | Quantity | Value | LCSC Part #
D1 | LED_D3.0mm | 1 | LED
J1 | PinHeader_1x06_P2.54mm_Vertical | 1 | Servo
J2 | PinHeader_1x05_P2.54mm_Vertical | 1 | CAN
R1 | R_Axial_DIN0207_L6.3mm_D2.5mm_P7.62mm_Horizontal | 1 | 470R
U1 | NUCLEO-F303K8 | 1 | NUCLEO-F303K8

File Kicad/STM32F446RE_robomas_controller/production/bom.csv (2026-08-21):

Designator | Footprint | Quantity | Value | LCSC Part #
D1 | LED_D3.0mm | 1 | Status_LED
J1 | PinHeader_1x02_P2.54mm_Vertical | 1 | UP_R
J2 | PinHeader_1x02_P2.54mm_Vertical | 1 | UP_DEG-
J3 | PinHeader_1x02_P2.54mm_Vertical | 1 | UP_DEG+
J4 | PinHeader_1x02_P2.54mm_Vertical | 1 | LOW_R
J5 | PinHeader_1x02_P2.54mm_Vertical | 1 | LOW_DEG-
J6 | PinHeader_1x02_P2.54mm_Vertical | 1 | LOW_DEG+
J7 | PinHeader_1x05_P2.54mm_Vertical | 1 | COMMAND_CAN
J8 | PinHeader_1x05_P2.54mm_Vertical | 1 | ROBOMAS_CAN
J9 | PinHeader_1x02_P2.54mm_Vertical | 1 | E5V
R1 | R_Axial_DIN0207_L6.3mm_D2.5mm_P7.62mm_Horizontal | 1 | 300R
U3 | MODULE_NUCLEO-F446RE_CN11_CN12_clearance | 1 | NUCLEO-F446RE

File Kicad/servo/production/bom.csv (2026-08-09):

Designator | Footprint | Quantity | Value | LCSC Part #
C1 | CP_Radial_D12.5mm_P5.00mm | 1 | 1000μF
C2 | C_Disc_D5.0mm_W2.5mm_P5.00mm | 1 | 0.1μF
D1 | LED_D3.0mm | 1 | LED
J1 | PinHeader_1x06_P2.54mm_Vertical | 1 | pwm
J2 | PinHeader_1x03_P2.54mm_Vertical | 1 | servo1
J3 | PinHeader_1x03_P2.54mm_Vertical | 1 | servo2
J4 | PinHeader_1x03_P2.54mm_Vertical | 1 | servo3
J5 | PinHeader_1x03_P2.54mm_Vertical | 1 | servo4
J6 | PinHeader_1x03_P2.54mm_Vertical | 1 | servo5
P1 | AMASS_XT30PW-M_1x02_P2.50mm_Horizontal | 1 | XT30
R1, R2, R3, R4, R5 | R_Axial_DIN0207_L6.3mm_D2.5mm_P7.62mm_Horizontal | 5 | 220Ω
R6 | R_Axial_DIN0207_L6.3mm_D2.5mm_P7.62mm_Horizontal | 1 | 1k

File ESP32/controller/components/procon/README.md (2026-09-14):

# ESP32/controller/components/procon

Bluetooth経由でプロコン(Nintendo Switch用コントローラー等)を接続し，スティック・ボタンの入力を取得するコンポーネント．Bluepad32/BTstackに依存する(Dev Containerでの依存取得については[リポジトリ直下のREADME.md](../../../../README.md)を参照)．

## スタックサイズについて

`my_platform.c`のコールバック群は，`app_main()`タスクで呼ばれるループ処理`btstack_run_loop_execute()`で呼ばれる．そのため，sdkconfigで決めることができる`CONFIG_ESP_MAIN_TASK_STACK_SIZE`は，
Bluetooth接続時などは，スタックが深くなり，デフォルトの3584だと足りなくなることがある．
そのため,`on_device_connected()`などが呼ばれるときのスタックの深さを，
```C
ESP_LOGI("STACK", "main task stack remaining (words): %u", uxTaskGetStackHighWaterMark(NULL));
```
で確認し，適切な大きさを設定すると良い．

もしくは，

```C
void bt_run_loop_task(void *arg){
    btstack_run_loop_execute(); // ここでnever return
}

void app_main(void){
    // ... 既存の初期化処理(arms_init(), can_init_and_start(), 各種xTaskCreateなど)は全部先にやっておく ...

    xTaskCreatePinnedToCore(
        bt_run_loop_task,
        "bt_run_loop",
        8192, // ここで明示的にサイズを指定。CONFIG_ESP_MAIN_TASK_STACK_SIZEとは独立
        NULL,
        1, // app main プライオリティ(ESP_TASK_MAIN_PRIO)はデフォルトでは1
        NULL,
        APP_CPU_NUM
    );

    // app_main()はここでreturnできる
}
```
として，sdkconfigの設定と切り離してコード内で管理できるようにすると良い．
このとき，`app_main()`はreturnすると割り当てられていたスタック領域(`CONFIG_ESP_MAIN_TASK_STACK_SIZE`)をヒープに返却する．

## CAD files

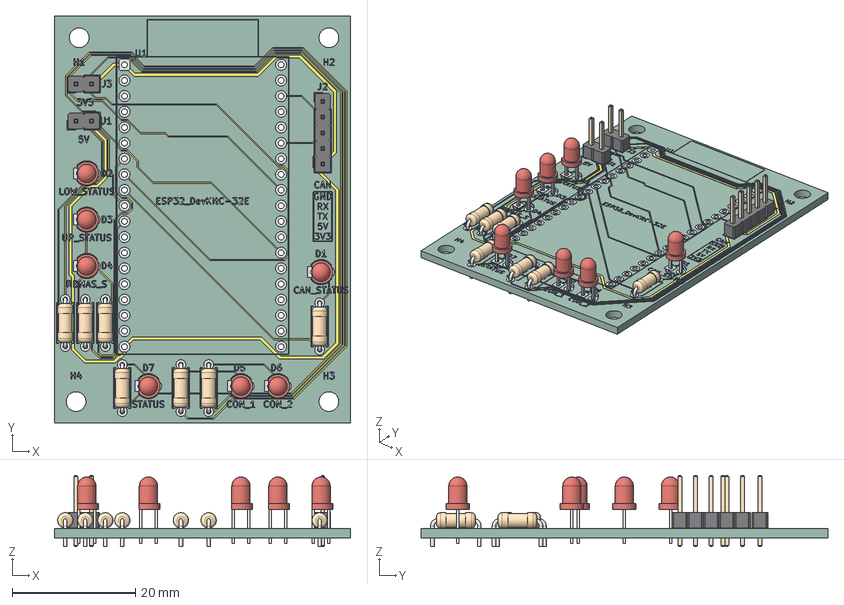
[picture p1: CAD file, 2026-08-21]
Kicad/ESP/.step
48.0 x 65.9 x 11.5 mm
R_Axial_DIN0207_L63mm_D25mm_P762mm_Horizontal x 7
PinHeader_1x02_P254mm_Vertical x 2
LED_D3.0mm x 7
PinHeader_1x05_P254mm_Vertical
ESP_copper
ESP_pad
ESP_silkscreen x 2
ESP_PCB

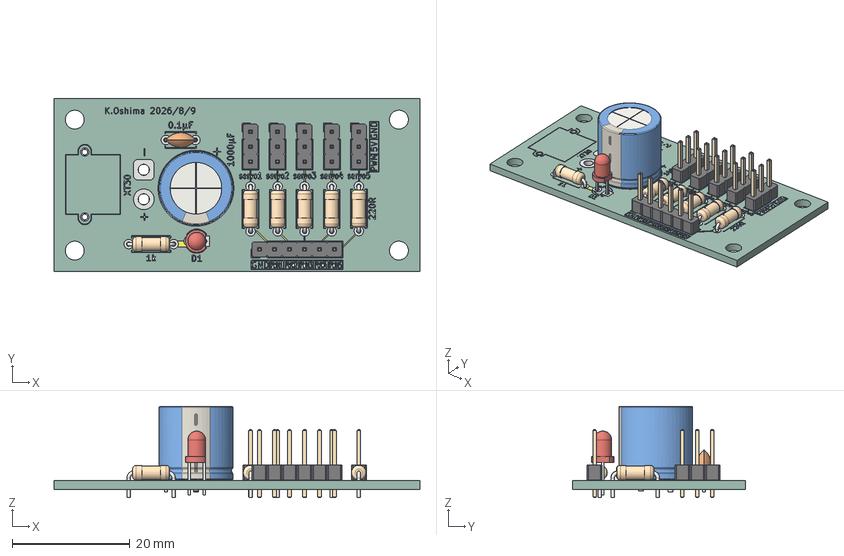
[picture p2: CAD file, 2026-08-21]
Kicad/servo/.step
62.0 x 29.3 x 15.5 mm
R_Axial_DIN0207_L63mm_D25mm_P762mm_Horizontal x 6
PinHeader_1x03_P254mm_Vertical x 5
LED_D3.0mm
PinHeader_1x06_P254mm_Vertical
C_Disc_D50mm_W25mm_P500mm
CP_Radial_D125mm_P500mm
servo_copper
servo_pad
servo_silkscreen x 2
servo_PCB

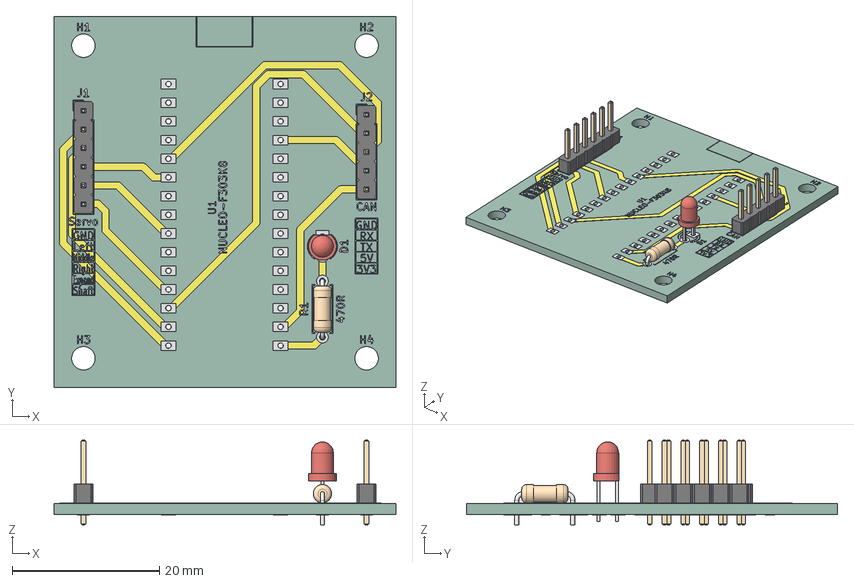
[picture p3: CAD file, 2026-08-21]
Kicad/STM32F303K8_lower_arm_servo/.step
46.5 x 50.5 x 11.5 mm
LED_D3.0mm
PinHeader_1x06_P254mm_Vertical
PinHeader_1x05_P254mm_Vertical
R_Axial_DIN0207_L63mm_D25mm_P762mm_Horizontal
STM32F303K8_lower_arm_servo_copper
STM32F303K8_lower_arm_servo_pad
STM32F303K8_lower_arm_servo_silkscreen x 2
STM32F303K8_lower_arm_servo_PCB

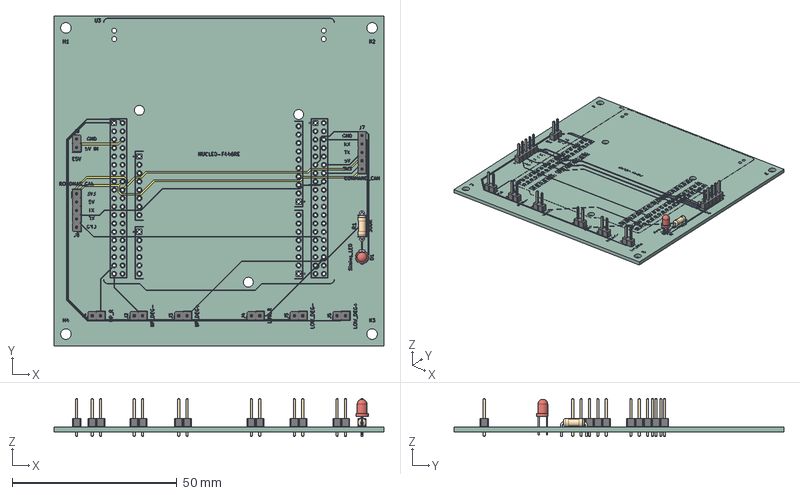
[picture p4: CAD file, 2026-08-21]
Kicad/STM32F446RE_robomas_controller/.step
100.0 x 100.0 x 11.5 mm
PinHeader_1x02_P254mm_Vertical x 7
R_Axial_DIN0207_L63mm_D25mm_P762mm_Horizontal
LED_D3.0mm
PinHeader_1x05_P254mm_Vertical x 2
STM32F446RE_robomas_controller_copper
STM32F446RE_robomas_controller_pad
STM32F446RE_robomas_controller_silkscreen x 2
STM32F446RE_robomas_controller_PCB

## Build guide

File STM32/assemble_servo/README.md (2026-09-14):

# STM32/assemble_servo

整理機構(Assemble)のサーボ角度を`CAN_ID_ASSEMBLE_COMMAND`(`common/can_protocol/README.md`参照)経由で制御する．

同じ回路基板(NUCLEO-F303K8，`Kicad/STM32F303K8_lower_arm_servo`)を使う[STM32/lower_arm_servo](../lower_arm_servo/README.md)と，ピン・タイマー設定・CAN送受信の基本パターンは共通．座標変換もホーミングも使わないため，`common/coordinate`・`common/arm`はリンクしていない．

## settings
### Pin

| 用途 | STM32ピン | CubeMX設定 | Nucleo端子 |
| --- | --- | --- | --- |
| Assemble | PB4 | TIM3_CH1 | D12 |
| CAN RX  | PA11 | CAN_RX | D10 |
| CAN TX  | PA12 | CAN_TX | D2 |
| STATUS_LED | PB3  | GPIO_Output | D13 |

### TIM

TIM3(PWM，20ms周期)．他プロジェクト(lower_arm_servo等)と同じ`Prescaler=7`, `Counter Period=19999`．

### CAN

Prescaler=1, BS1=6TQ, BS2=1TQ, SJW=1TQ (他のF303K8プロジェクトと共通，1Mbps)．

## Code

```C
/* USER CODE BEGIN PD */
#define SERVO_0   500
#define SERVO_270 2500
#define SERVO_DEG_RANGE 270 //サーボの角度(0-270deg)とパルス幅(SERVO_0-SERVO_270)の換算に使う定数

#define STATUS_LED_BLINK_MS 200 //異常時のLED点滅間隔
```

```C
/* USER CODE BEGIN Private defines */
#define ASSEMBLE_htim htim3
#define ASSEMBLE_TIM_CHANNEL TIM_CHANNEL_1
```

### CAN

`CAN_ID_ASSEMBLE_COMMAND`(DLC=1，角度指令0〜90°)を受信すると，機構の可動域(`ASSEMBLE_DEG_RANGE`=90，`common/can_protocol/inc/can_protocol.h`で定義)にクランプした上でサーボPWMに変換して出力する．

ホーミングには関与しないため，`CAN_ID_ASSEMBLE_COMMAND`以外のCAN IDは無視する．

```C
/* USER CODE BEGIN 0 */
void HAL_CAN_RxFifo0MsgPendingCallback(CAN_HandleTypeDef *hcan){
  CAN_RxHeaderTypeDef rx_header;
  can_data_t rx_data = {0};
  if(hcan->Instance != CAN)return;
  if(HAL_CAN_GetRxMessage(hcan,CAN_RX_FIFO0,&rx_header,rx_data.raw) != HAL_OK)return;

  switch (rx_header.StdId) {
  case CAN_ID_ASSEMBLE_COMMAND: {
    assemble_deg_t deg = rx_data.assemble_deg;
    if(deg > ASSEMBLE_DEG_RANGE) deg = ASSEMBLE_DEG_RANGE; //機構の可動域(0-90度)にクランプ
    __HAL_TIM_SET_COMPARE(&ASSEMBLE_htim,ASSEMBLE_TIM_CHANNEL,
      (uint16_t)((double)deg / SERVO_DEG_RANGE * (SERVO_270 - SERVO_0) + SERVO_0));
    break;
  }
  default:
    break;
  }
}
```

Assembleには`common/can_protocol`が定義するHeartbeat CAN IDが無いため，ESP32側の`micon_connection`による生存監視の対象外(詳細は[common/can_protocol/README.md](../../common/can_protocol/README.md)参照)．

### Status_LED

CANのバスオフ／エラーパッシブ／エラーワーニングいずれかを検知したら異常状態としてラッチし，`STATUS_LED_BLINK_MS`(200ms)間隔で点滅させる．正常時は常時点灯．

```C
/* USER CODE BEGIN 3 */
//CANバスエラー(バスオフ/エラーパッシブ/エラーワーニング)を検知したらラッチする
if(__HAL_CAN_GET_FLAG(&hcan, CAN_FLAG_BOF) ||
   __HAL_CAN_GET_FLAG(&hcan, CAN_FLAG_EPV) ||
   __HAL_CAN_GET_FLAG(&hcan, CAN_FLAG_EWG)){
  can_bus_error = 1;
}

if(can_bus_error){
  //異常時: 点滅
  uint32_t now = HAL_GetTick();
  if(now - status_led_last_toggle >= STATUS_LED_BLINK_MS){
    status_led_last_toggle = now;
    HAL_GPIO_TogglePin(STATUS_LED_GPIO_Port, STATUS_LED_Pin);
  }
}else{
  //正常動作中: 点灯
  HAL_GPIO_WritePin(STATUS_LED_GPIO_Port, STATUS_LED_Pin, GPIO_PIN_SET);
}
```

### Error_Handler

初期化失敗などでHALの割り込みが止まり`HAL_GetTick()`が進まなくなった場合に備え，`Error_Handler()`内ではタイマー割り込みに頼らないソフトウェアループでLEDを点滅させる．

```C
/* USER CODE BEGIN Error_Handler_Debug */
__disable_irq();
while (1)
{
  HAL_GPIO_TogglePin(STATUS_LED_GPIO_Port, STATUS_LED_Pin);
  for(volatile uint32_t i = 0; i < 400000; i++){}
}
```

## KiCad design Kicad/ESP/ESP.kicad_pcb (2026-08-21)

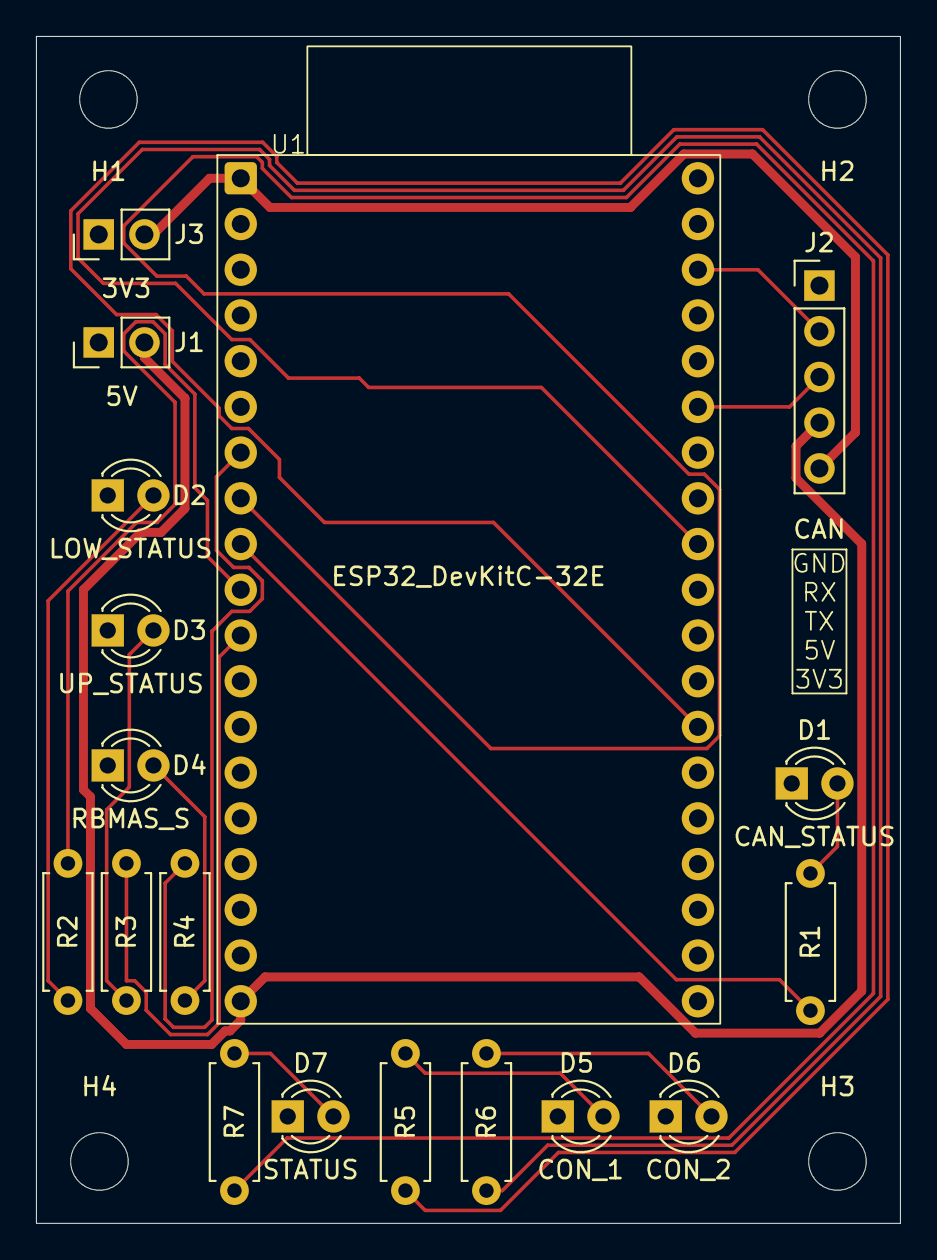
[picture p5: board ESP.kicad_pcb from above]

Board: 2 copper layers, 48.0 x 65.9 mm, 22 parts (0 on the bottom side), 19 nets.

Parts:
D1: CAN_STATUS; LED_D3.0mm
D2: LOW_STATUS; LED_D3.0mm
D3: UP_STATUS; LED_D3.0mm
D4: RBMAS_S; LED_D3.0mm
D5: CON_1; LED_D3.0mm
D6: CON_2; LED_D3.0mm
D7: STATUS; LED_D3.0mm
H1, H2, H3, H4: MountingHole; MountingHole_3.2mm_M3
J1: 5V; PinHeader_1x02_P2.54mm_Vertical
J2: CAN; PinHeader_1x05_P2.54mm_Vertical
J3: 3V3; PinHeader_1x02_P2.54mm_Vertical
R1, R2, R3, R4, R5, R6, R7: 300R; R_Axial_DIN0207_L6.3mm_D2.5mm_P7.62mm_Horizontal
U1: ESP32_DevKitC-32E; ESP32_DevKitC_32E

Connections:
+3.3V: J2.5, J3.2, U1.1 (3V3)
+5V: J1.2, J2.4, U1.19 (5V)
/CAN_RX: J2.2, U1.22 (GPIO22)
/CAN_STATUS_LED_GPIO: R1.1, U1.9 (GPIO25)
/CAN_TX: J2.3, U1.25 (GPIO21)
/CONTROLLER_1_LED_GPIO: R5.1, U1.32 (GPIO4)
/CONTROLLER_2_LED_GPIO: R6.1, U1.28 (GPIO18)
/LOWER_ARM_STATUS_LED_GPIO: R2.1, U1.10 (GPIO26)
/ROBOMAS_CONTROLLER_STATUS_LED_GPIO: R4.1, U1.7 (GPIO32)
/STATUS_LED_GPIO: R7.1, U1.8 (GPIO33)
/UPPER_ARM_STATUS_LED_GPIO: R3.1, U1.11 (GPIO27)
GND: D1.1 (K), D2.1 (K), D3.1 (K), D4.1 (K), D5.1 (K), D6.1 (K), D7.1 (K), J1.1, J2.1, J3.1, U1.14 (GND), U1.20 (GND), U1.26 (GND)
unnamed: D1.2 (A), R1.2
unnamed: D2.2 (A), R2.2
unnamed: D3.2 (A), R3.2
unnamed: D4.2 (A), R4.2
unnamed: D5.2 (A), R5.2
unnamed: D6.2 (A), R6.2
unnamed: D7.2 (A), R7.2

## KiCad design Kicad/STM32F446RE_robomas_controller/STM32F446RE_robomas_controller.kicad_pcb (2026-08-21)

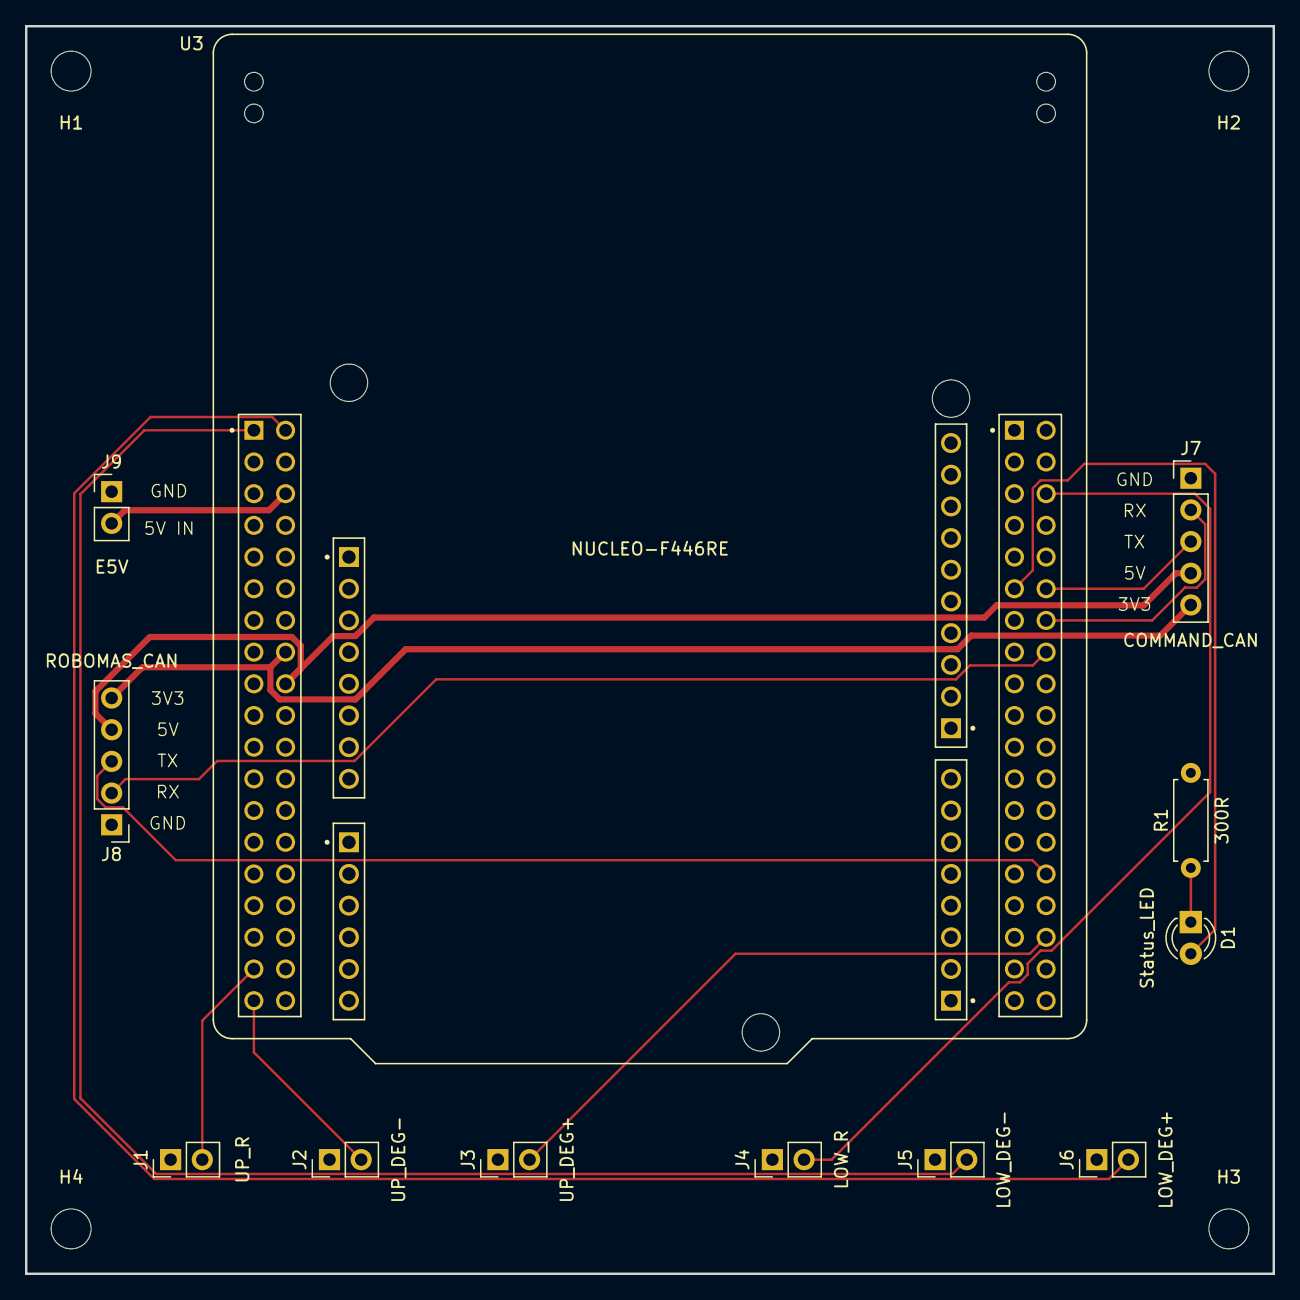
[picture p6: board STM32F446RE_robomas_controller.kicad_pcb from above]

Board: 2 copper layers, 100.0 x 100.0 mm, 16 parts (0 on the bottom side), 16 nets.

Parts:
D1: Status_LED; LED_D3.0mm
H1, H2, H3, H4: MountingHole; MountingHole_3.2mm_M3
J1: UP_R; PinHeader_1x02_P2.54mm_Vertical
J2: UP_DEG-; PinHeader_1x02_P2.54mm_Vertical
J3: UP_DEG+; PinHeader_1x02_P2.54mm_Vertical
J4: LOW_R; PinHeader_1x02_P2.54mm_Vertical
J5: LOW_DEG-; PinHeader_1x02_P2.54mm_Vertical
J6: LOW_DEG+; PinHeader_1x02_P2.54mm_Vertical
J7: COMMAND_CAN; PinHeader_1x05_P2.54mm_Vertical
J8: ROBOMAS_CAN; PinHeader_1x05_P2.54mm_Vertical
J9: E5V; PinHeader_1x02_P2.54mm_Vertical
R1: 300R; R_Axial_DIN0207_L6.3mm_D2.5mm_P7.62mm_Horizontal
U3: NUCLEO-F446RE; MODULE_NUCLEO-F446RE_CN11_CN12_clearance

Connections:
+3.3V: J7.5, J8.5, U3.CN7_16 (CN7_+3V3)
+5V: J7.4, J8.4, U3.CN7_18 (CN7_+5V)
/COMMAND_CAN_RX: J7.2, U3.CN10_14 (PA11)
/COMMAND_CAN_TX: J7.3, U3.CN10_12 (PA12)
/E5V: J9.2, U3.CN7_6 (E5V)
/LOWER_ARM_DEG_OVER_LIMIT: J6.2, U3.CN7_2 (PC11)
/LOWER_ARM_DEG_UNDER_LIMIT: J5.2, U3.CN7_1 (PC10)
/LOWER_ARM_R_LIMIT: J4.2, U3.CN10_6 (PC5)
/ROBOMAS_CAN_RX: J8.2, U3.CN10_16 (PB12)
/ROBOMAS_CAN_TX: J8.3, U3.CN10_30 (PB13)
/Status_LED: D1.2 (A), U3.CN10_11 (PA5)
/UPPER_ARM_DEG_OVER_LIMIT: J3.2, U3.CN10_34 (PC4)
/UPPER_ARM_DEG_UNDER_LIMIT: J2.2, U3.CN7_37 (PC3)
/UPPER_ARM_R_LIMIT: J1.2, U3.CN7_35 (PC2)
GND: J1.1, J2.1, J3.1, J4.1, J5.1, J6.1, J7.1, J8.1, J9.1, R1.2, U3.CN7_8 (CN7_GND), U3.CN7_19 (CN7_GND__1), U3.CN7_20 (CN7_GND__2), U3.CN7_22 (CN7_GND__3), U3.CN10_9 (CN10_GND), U3.CN10_20 (CN10_GND__1), U3.CN10_32 (AGND)
unnamed: D1.1 (K), R1.1

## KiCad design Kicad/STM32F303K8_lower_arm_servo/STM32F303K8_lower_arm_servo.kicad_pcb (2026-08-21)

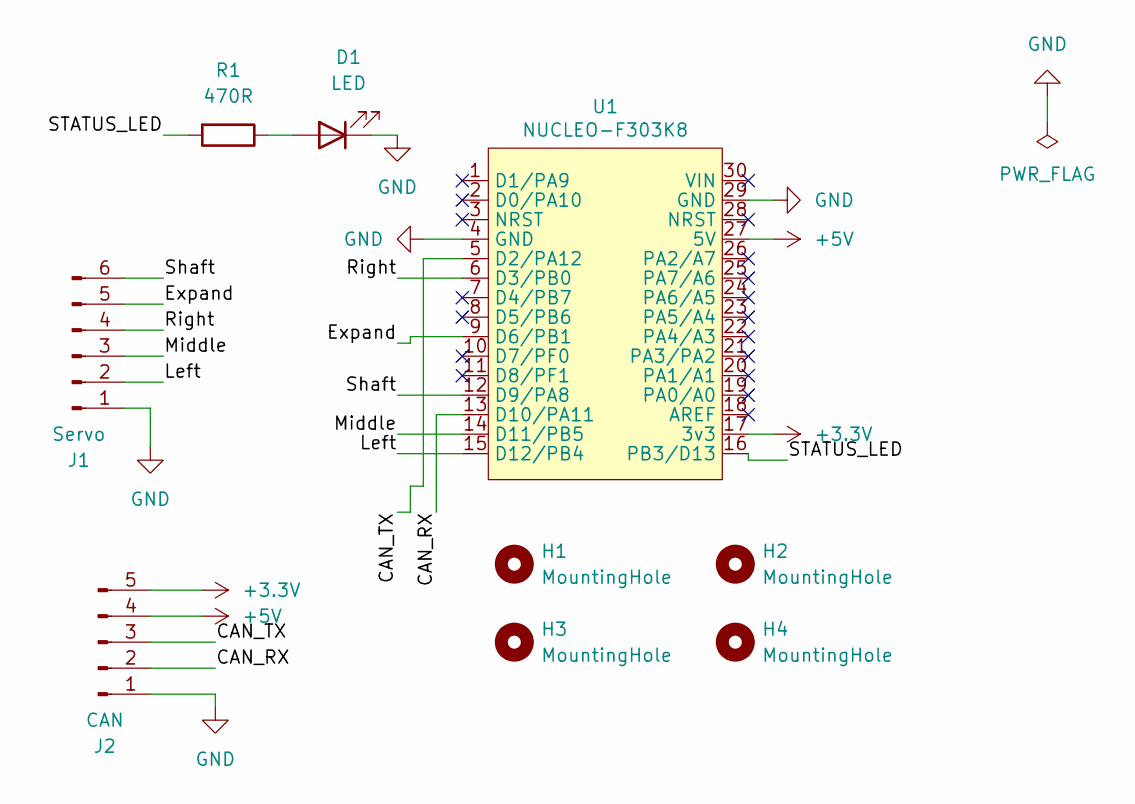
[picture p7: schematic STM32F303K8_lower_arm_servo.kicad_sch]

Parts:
D1: LED; LED_D3.0mm
H1, H2, H3, H4: MountingHole; MountingHole_3.2mm_M3
J1: Servo; PinHeader_1x06_P2.54mm_Vertical
J2: CAN; PinHeader_1x05_P2.54mm_Vertical
R1: 470R; R_Axial_DIN0207_L6.3mm_D2.5mm_P7.62mm_Horizontal
U1: NUCLEO-F303K8

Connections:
+3.3V: J2.5, U1.17 (3v3)
+5V: J2.4, U1.27 (5V)
/CAN_RX: J2.2, U1.13 (D10/PA11)
/CAN_TX: J2.3, U1.5 (D2/PA12)
/Expand: J1.5, U1.9 (D6/PB1)
/Left: J1.2, U1.15 (D12/PB4)
/Middle: J1.3, U1.14 (D11/PB5)
/Right: J1.4, U1.6 (D3/PB0)
/STATUS_LED: R1.2, U1.16 (PB3/D13)
/Shaft: J1.6, U1.12 (D9/PA8)
GND: D1.1 (K), J1.1, J2.1, U1.4 (GND), U1.29 (GND)
unnamed: D1.2 (A), R1.1

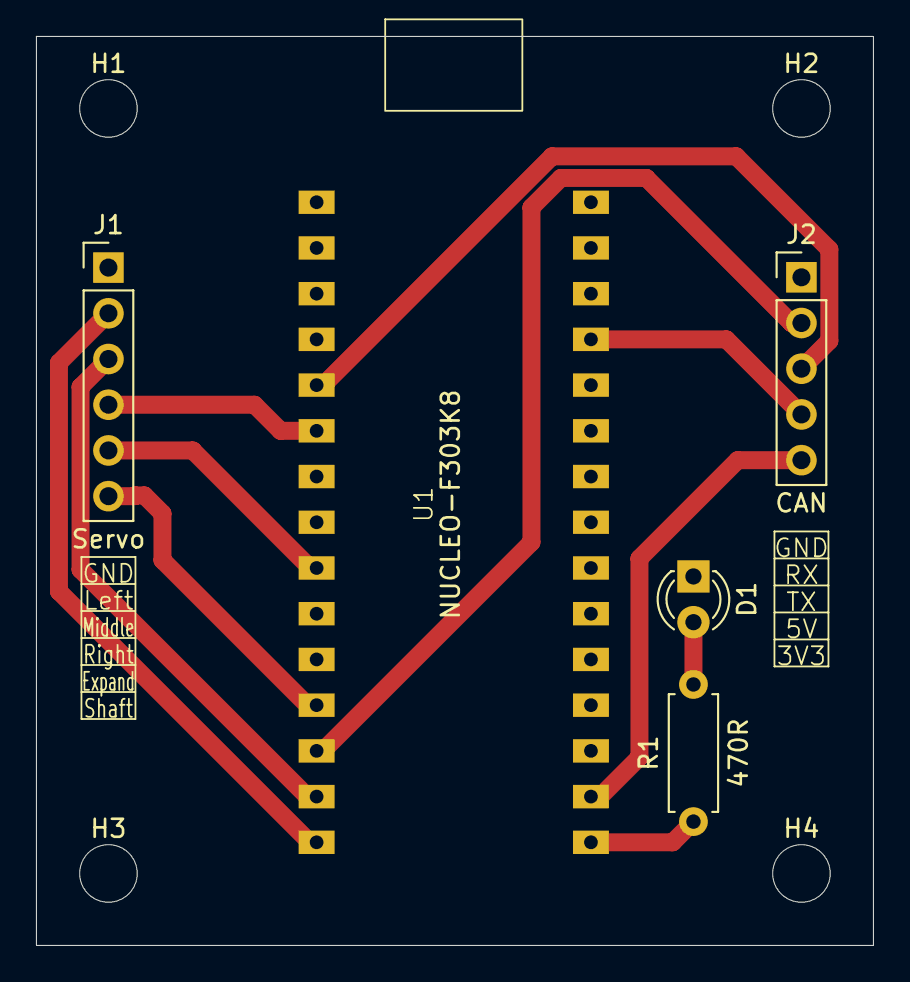
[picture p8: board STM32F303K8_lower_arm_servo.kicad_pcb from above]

Board: 2 copper layers, 46.5 x 50.5 mm, 9 parts (0 on the bottom side), 12 nets.

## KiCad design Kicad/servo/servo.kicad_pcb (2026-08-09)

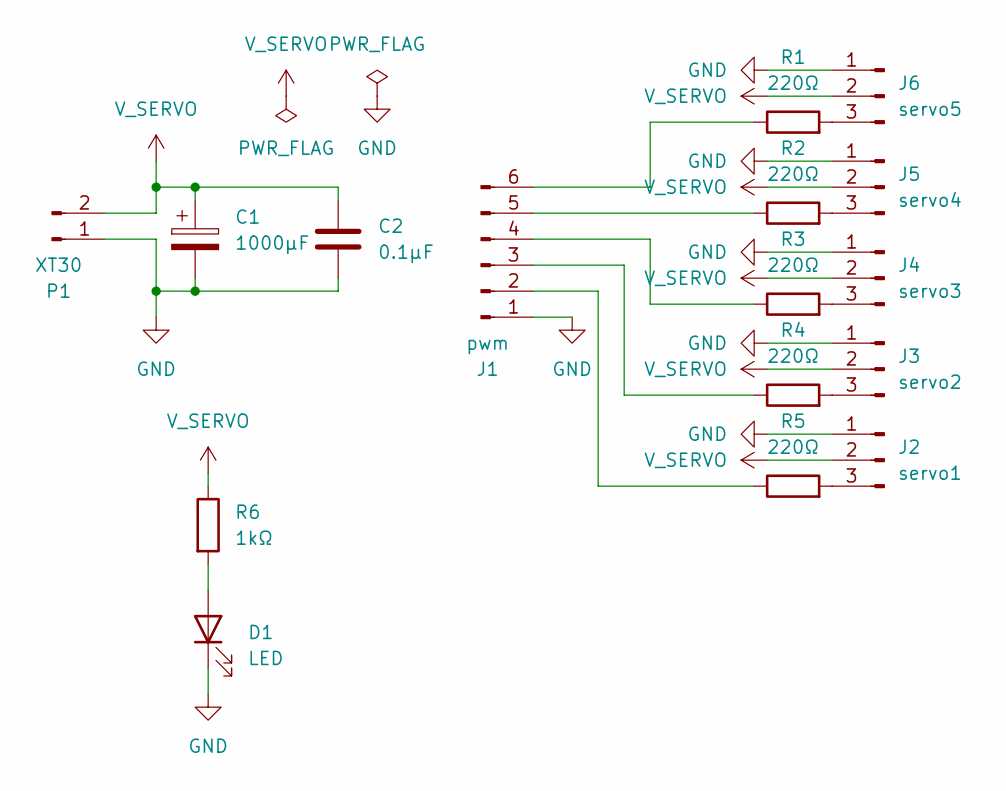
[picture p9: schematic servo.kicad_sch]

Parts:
C1: 1000μF; CP_Radial_D12.5mm_P5.00mm
C2: 0.1μF; C_Disc_D5.0mm_W2.5mm_P5.00mm
D1: LED; LED_D3.0mm
J1: pwm; PinHeader_1x06_P2.54mm_Vertical
J2: servo1; PinHeader_1x03_P2.54mm_Vertical
J3: servo2; PinHeader_1x03_P2.54mm_Vertical
J4: servo3; PinHeader_1x03_P2.54mm_Vertical
J5: servo4; PinHeader_1x03_P2.54mm_Vertical
J6: servo5; PinHeader_1x03_P2.54mm_Vertical
P1: XT30; AMASS_XT30PW-M_1x02_P2.50mm_Horizontal
R1, R2, R3, R4, R5: 220Ω; R_Axial_DIN0207_L6.3mm_D2.5mm_P7.62mm_Horizontal
R6: 1kΩ; R_Axial_DIN0207_L6.3mm_D2.5mm_P7.62mm_Horizontal

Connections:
GND: C1.2, C2.2, D1.1 (K), J1.1, J2.1, J3.1, J4.1, J5.1, J6.1, P1.1
unnamed: D1.2 (A), R6.2
unnamed: J1.2, R5.1
unnamed: J1.3, R4.1
unnamed: J1.4, R3.1
unnamed: J1.5, R2.1
unnamed: J1.6, R1.1
unnamed: J2.3, R5.2
unnamed: J3.3, R4.2
unnamed: J4.3, R3.2
unnamed: J5.3, R2.2
unnamed: J6.3, R1.2
V_SERVO: C1.1, C2.1, J2.2, J3.2, J4.2, J5.2, J6.2, P1.2, R6.1

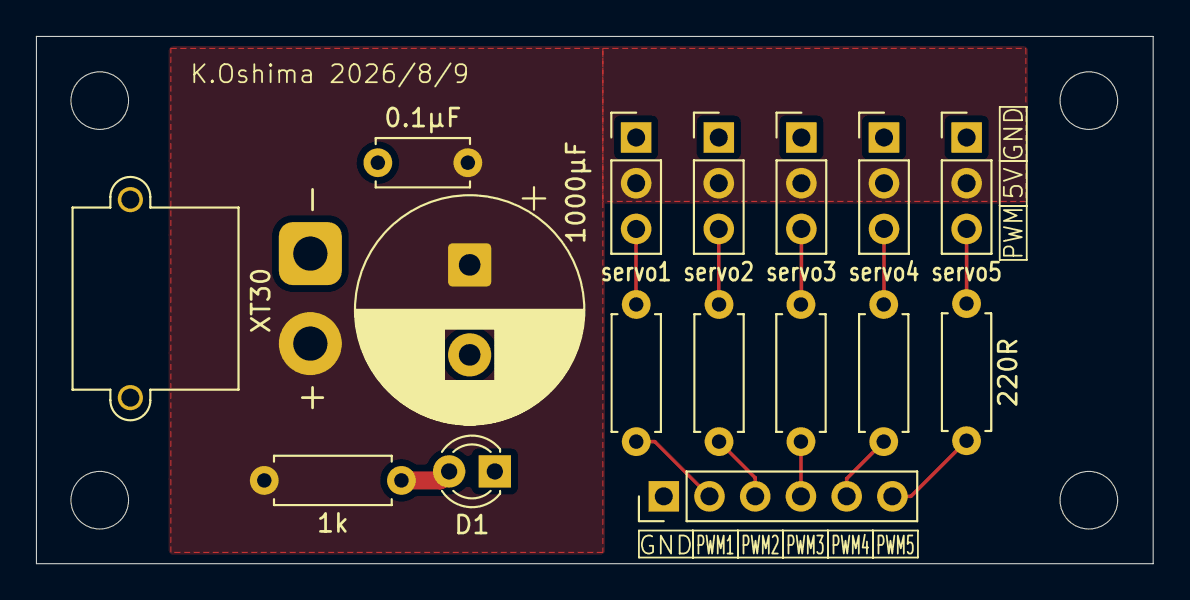
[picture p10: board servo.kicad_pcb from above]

Board: 2 copper layers, 62.0 x 29.3 mm, 16 parts (0 on the bottom side), 13 nets.

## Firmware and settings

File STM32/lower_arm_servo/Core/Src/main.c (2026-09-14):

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
/* Includes ------------------------------------------------------------------*/
#include "main.h"

/* USER CODE BEGIN Includes */
#include "can_protocol.h"
#include "coordinate.h"
#include "arm.h"
#include "stm_can.h"
#include <math.h>
#include <stdbool.h>
/* USER CODE END Includes */

/* USER CODE BEGIN PD */
#define SERVO_0   500
#define SERVO_270 2500
// Left/Middle/Rightハンドの中間角度(HAND_STATE_HOLD/HAND_STATE_CATCH)のパルス幅
// SERVO_0(0度)~SERVO_270(270度)を基準に角度から線形補間する
#define SERVO_45  833
#define SERVO_225 2167

#define SERVO_150 1622
#define SERVO_120 1388

// ROBOT_TEAM(出場チーム 青/赤)はcommon/arm/inc/arm.hで定義される。
// ESP32/STM32の全ファームウェアで共有する値なので，このファイルでは再定義しない。
// (競技開始前に決定した後は変更しない。緊急停止スイッチが押されるとESP32/STM32の
//  各基板は再起動するため，実行時にトグルする方式では状態を保持できない。そのため，
//  チームに応じてarm.h側の値を書き換えてビルド・書き込みすることで固定する。)

// Status_LEDでLeft->Middle->Right->Expandの順に各chの状態を点滅回数で表示する
// 長いマーカー点灯(周期の開始) -> 各chごとに短い点滅(ON:2回 OFF:1回) -> 一定時間消灯 の繰り返し
#define STATUS_LED_MARKER_MS     1000 //周期の始まりを示す長い点灯
#define STATUS_LED_BLINK_MS      100  //1回分の点滅の点灯時間
#define STATUS_LED_INTRA_GAP_MS  100  //ONの2回点滅の間の消灯時間
#define STATUS_LED_CHANNEL_GAP_MS 700 //ch同士の間，およびマーカー直後の消灯時間(繋がって見えないように)
#define STATUS_LED_END_PAUSE_MS  1200 //4ch分表示し終えてから次のマーカーまでの消灯時間
#define LOOP_MS 2
/* USER CODE END PD */

CAN_HandleTypeDef hcan;

TIM_HandleTypeDef htim1;
TIM_HandleTypeDef htim3;

UART_HandleTypeDef huart2;

/* USER CODE BEGIN PV */
CAN_RxHeaderTypeDef rx_header;
can_data_t rx_data = {0};

// 現在のLeft/Middle/Rightの状態(hand_state_t)とExpandの状態(true=ON)．Status_LEDの点滅表示に使う
hand_state_t lower_arm_left, lower_arm_middle, lower_arm_right;
bool lower_arm_expand;

typedef enum{
  STATUS_LED_STATE_MARKER,          //周期開始の長い点灯
  STATUS_LED_STATE_CHANNEL_GAP,     //ch移行時(マーカー直後含む)の消灯
  STATUS_LED_STATE_BLINK_ON,        //点滅の点灯中
  STATUS_LED_STATE_BLINK_GAP,       //点滅の点灯の間，または最後の点滅後の消灯
  STATUS_LED_STATE_END_PAUSE,       //4ch分表示し終えた後の消灯
}status_led_state_t;

status_led_state_t status_led_state;
uint32_t status_led_phase_start;
uint8_t status_led_channel_index;     //現在表示中のch(0:Left 1:Middle 2:Right 3:Expand)
uint8_t status_led_blinks_remaining;  //現在のchで残っている点滅回数

/* USER CODE END PV */

void SystemClock_Config(void);
static void MX_GPIO_Init(void);
static void MX_USART2_UART_Init(void);
static void MX_CAN_Init(void);
static void MX_TIM1_Init(void);
static void MX_TIM3_Init(void);
/* USER CODE BEGIN 0 */

/**
* @brief 座標から，Shaftサーボの目標角度(度，0~270度のうちSERVO角度と対応する値)を計算する．
*        (upper_arm_servoのshaft_deg_from_arm_deg()と同じ考え方。そちらも参照)
*
*        Shaftは可動範囲270度のうち中央の180度(45~225度)だけを通常使用域とし，アームの
*        可動域(LOWER_ARM_DEG_MIN~LOWER_ARM_DEG_MIN+LOWER_ARM_DEG_RANGE)の中央
*        (=アームが真上向きの位置，偏角90度)がShaft使用域の中央(135度)に一致するよう，
*        偏角にオフセットを足すだけの単純な線形対応にする。
*
*        LOWER_ARM_DEG_MINは0度で，かつto_polar()の値域[0,2π)の境界と重ならないため，
*        upper_arm_servoと違い0度付近のラップ補正は不要。
*
*        赤チームのホーミング原点(LOWER_ARM_DEG_MIN=0度)ではSERVO_45，
*        青チームのホーミング原点(LOWER_ARM_DEG_MIN+RANGE=180度)ではSERVO_225になる。
*/
static double shaft_deg_from_arm_deg(direct_t direct){
  double deg = to_polar(direct).theta / (2 * M_PI) * 360.0;
  // アーム可動域の中央(真上向き)をShaft使用域の中央(135度)に合わせるオフセット
  return deg - (LOWER_ARM_DEG_MIN + LOWER_ARM_DEG_RANGE / 2.0) + 135.0;
}

/**
* @brief ホーミング原点(LOWER_ARM_HOME_COORDINATE，common/arm/inc/arm.h参照)に対応する
*        Shaftのパルス幅を計算する。
*        ホーミング完了後，ESP32はshaft_rotate/shaft_fineを0にリセットしてから
*        x/yをLOWER_ARM_HOME_COORDINATEにしたCAN_ID_LOWER_ARM_COMMANDを送ってくるため，
*        その時に計算されるパルス幅と同じ値になる(CAN_ID_LOWER_ARM_COMMAND側の計算式参照)。
*        hand_fold()でホーミング開始時点からこの角度にしておくことで，ホーミング完了時に
*        ハンドの向きが変わらないようにする。
*/
static uint32_t shaft_home_pulse(){
  direct_t home = LOWER_ARM_HOME_COORDINATE;
  double shaft_theta = shaft_deg_from_arm_deg(home) * M_PI / 180.0;
  double shaft_pulse = shaft_theta * (SERVO_270 - SERVO_0) / (3 * M_PI_2) + SERVO_0;
  return (uint32_t)shaft_pulse;
}

/**
* @brief ハンドをたたむ
 */
static void hand_fold(){
    __HAL_TIM_SET_COMPARE(&Left_htim,Left_TIM_CHANNEL,SERVO_0);
    __HAL_TIM_SET_COMPARE(&Middle_htim,Middle_TIM_CHANNEL,SERVO_270);
    __HAL_TIM_SET_COMPARE(&Right_htim,Right_TIM_CHANNEL,SERVO_270);
    __HAL_TIM_SET_COMPARE(&Expand_htim,Expand_TIM_CHANNEL,SERVO_270);
    // Shaft(ハンドの向き)は，たたんだ状態にはせずホーミング原点の向きのままにしておく
    __HAL_TIM_SET_COMPARE(&Shaft_htim,Shaft_TIM_CHANNEL,shaft_home_pulse());
}

/**
* @brief 計算したパルス幅を可動域(SERVO_0~SERVO_270)にクランプする．
*        Shaftはshaft_rotate/shaft_fineの加算で可動域を超えることがあるため，
*        クランプした分だけ回転(または微調整)が適用されないことを許容する。
*/
static uint32_t clamp_servo_pulse(double pulse){
  if(pulse < SERVO_0)return SERVO_0;
  if(pulse > SERVO_270)return SERVO_270;
  return (uint32_t)pulse;
}

/**
* @brief hand_state_t(RELEASE/HOLD/CATCH)を対応するサーボのパルス幅に変換する．
*        LeftとMiddle/Rightはサーボの取り付け向きが逆なので，同じ状態でもパルス幅が
*        異なる。どのハンドの状態かをポインタの一致で判別して振り分ける。
*/
static uint32_t hand_state_to_pulse(hand_state_t *state){
  if(state == NULL)return 0;
  if(state == &lower_arm_left){
    switch(*state){
      case HAND_STATE_HOLD:  return SERVO_45;
      case HAND_STATE_CATCH: return SERVO_150;
      case HAND_STATE_RELEASE:
      default:                return SERVO_0;
    }
  }else{
    switch(*state){
      case HAND_STATE_HOLD:  return SERVO_225;
      case HAND_STATE_CATCH: return SERVO_120;
      case HAND_STATE_RELEASE:
      default:                return SERVO_270;
    }
  }
  
}

void HAL_CAN_RxFifo0MsgPendingCallback(CAN_HandleTypeDef *hcan){
  if(hcan->Instance != CAN)return;
  if(HAL_CAN_GetRxMessage(hcan,CAN_RX_FIFO0,&rx_header,rx_data.raw) != HAL_OK)return;

  switch (rx_header.StdId) {
  case CAN_ID_LOWER_ARM_COMMAND:
    lower_arm_left   = (hand_state_t)rx_data.lower_arm.left;
    lower_arm_middle = (hand_state_t)rx_data.lower_arm.middle;
    lower_arm_right  = (hand_state_t)rx_data.lower_arm.right;
    lower_arm_expand = rx_data.lower_arm.expand;

    __HAL_TIM_SET_COMPARE(&Left_htim,Left_TIM_CHANNEL,hand_state_to_pulse(&lower_arm_left));
    __HAL_TIM_SET_COMPARE(&Middle_htim,Middle_TIM_CHANNEL,hand_state_to_pulse(&lower_arm_middle));
    __HAL_TIM_SET_COMPARE(&Right_htim,Right_TIM_CHANNEL,hand_state_to_pulse(&lower_arm_right));
    if(rx_data.lower_arm.expand){__HAL_TIM_SET_COMPARE(&Expand_htim,Expand_TIM_CHANNEL,SERVO_0);}else{__HAL_TIM_SET_COMPARE(&Expand_htim,Expand_TIM_CHANNEL,SERVO_270);}
    direct_t direct = {.x = rx_data.lower_arm.x, .y = rx_data.lower_arm.y};
    // アームの偏角を，真上向き(90度)がShaft135度になるようオフセットした角度にする
    // (shaft_deg_from_arm_deg()参照)。
    double shaft_theta = shaft_deg_from_arm_deg(direct) * M_PI / 180.0;
    // shaft_rotate=1のとき，アーム軸の回転によらずハンドの向きを180度回転させる。
    // 270度サーボのうち普段使うのは可動範囲分の180度だけなので，回転方向側の残り90度分の
    // 余裕を超える(=可動範囲の反対側まで回転しきれない)場合は，下のclamp_servo_pulse()で
    // パルス幅がクランプされ，それ以上は回転しない(毎回サーボを取り替える運用はしない)。
    // 整理機構は赤/青チームで左右逆側に取り付けるため(arm.h参照)，余裕が生まれる側(=回転
    // させる方向)もチームで逆になる。青は+M_PI(高いパルス側に余裕)，赤は-M_PI(低いパルス側に
    // 余裕)とする。
#if ROBOT_TEAM == ROBOT_TEAM_BLUE
    if(rx_data.lower_arm.shaft_rotate){shaft_theta += M_PI;}
#else
    if(rx_data.lower_arm.shaft_rotate){shaft_theta -= M_PI;}
#endif
    // シャフト角度の微調整(度)。L/Rの押しっぱなしでESP32側が加減算した値をそのまま加える
    shaft_theta += rx_data.lower_arm.shaft_fine * M_PI / 180.0;
    double shaft_pulse = shaft_theta * (SERVO_270 - SERVO_0) / (3 * M_PI_2) + SERVO_0;
    __HAL_TIM_SET_COMPARE(&Shaft_htim,Shaft_TIM_CHANNEL,clamp_servo_pulse(shaft_pulse));
    break;

  case CAN_ID_LOWER_HOMING:
    lower_arm_left = HAND_STATE_RELEASE;
    lower_arm_middle = HAND_STATE_RELEASE;
    lower_arm_right = HAND_STATE_RELEASE;
    lower_arm_expand = false;

    hand_fold();
    break;


  default:
    break;
  }
}

/**
* @brief chのindex(0:Left 1:Middle 2:Right 3:Expand)から現在の状態(true=ON)を返す．
*        Left/Middle/RightはHAND_STATE_RELEASE以外(HOLD/CATCH)であればONとして扱う．
*/
static bool status_led_channel_value(uint8_t channel_index){
  switch(channel_index){
    case 0: return lower_arm_left   != HAND_STATE_RELEASE;
    case 1: return lower_arm_middle != HAND_STATE_RELEASE;
    case 2: return lower_arm_right  != HAND_STATE_RELEASE;
    default: return lower_arm_expand;
  }
}

/**
* @brief Status_LEDに，先頭の長いマーカー点灯に続けてLeft->Middle->Right->Expandの
*        順で各chの状態を点滅回数で表示する．ONは2回，OFFは1回の短い点滅．
*        ch同士の間には必ず消灯を挟むので，何回点滅したかを数えればON/OFFが分かる．
*        4ch分表示し終えたら一定時間消灯してから，再びマーカーに戻る．
*        周期的(mainループ毎)に呼び出すこと．
*/
void status_led_update(){
  uint32_t now = HAL_GetTick();
  uint32_t elapsed = now - status_led_phase_start;

  switch(status_led_state){
  case STATUS_LED_STATE_MARKER:
    if(elapsed >= STATUS_LED_MARKER_MS){
      status_led_state = STATUS_LED_STATE_CHANNEL_GAP;
      status_led_channel_index = 0;
      status_led_phase_start = now;
    }
    break;

  case STATUS_LED_STATE_CHANNEL_GAP:
    if(elapsed >= STATUS_LED_CHANNEL_GAP_MS){
      status_led_blinks_remaining = status_led_channel_value(status_led_channel_index) ? 2 : 1;
      status_led_state = STATUS_LED_STATE_BLINK_ON;
      status_led_phase_start = now;
    }
    break;

  case STATUS_LED_STATE_BLINK_ON:
    if(elapsed >= STATUS_LED_BLINK_MS){
      status_led_blinks_remaining--;
      status_led_state = STATUS_LED_STATE_BLINK_GAP;
      status_led_phase_start = now;
    }
    break;

  case STATUS_LED_STATE_BLINK_GAP:
    if(status_led_blinks_remaining > 0){
      // 同じchの2回目の点滅がまだ残っている
      if(elapsed >= STATUS_LED_INTRA_GAP_MS){
        status_led_state = STATUS_LED_STATE_BLINK_ON;
        status_led_phase_start = now;
      }
    }else{
      // このchの表示は終わり
      if(elapsed >= STATUS_LED_CHANNEL_GAP_MS){
        status_led_channel_index++;
        status_led_phase_start = now;
        if(status_led_channel_index >= 4){
          status_led_state = STATUS_LED_STATE_END_PAUSE;
        }else{
          status_led_blinks_remaining = status_led_channel_value(status_led_channel_index) ? 2 : 1;
          status_led_state = STATUS_LED_STATE_BLINK_ON;
        }
      }
    }
    break;

  case STATUS_LED_STATE_END_PAUSE:
    if(elapsed >= STATUS_LED_END_PAUSE_MS){
      status_led_state = STATUS_LED_STATE_MARKER;
      status_led_phase_start = now;
    }
    break;
  }

  bool on = (status_led_state == STATUS_LED_STATE_MARKER) ||
            (status_led_state == STATUS_LED_STATE_BLINK_ON);
  HAL_GPIO_WritePin(
    STATUS_LED_GPIO_Port,
    STATUS_LED_Pin,
    on ? GPIO_PIN_SET : GPIO_PIN_RESET
  );
}
/* USER CODE END 0 */

/**
  * @brief  The application entry point.
  * @retval int
  */
int main(void)
{

  /* MCU Configuration--------------------------------------------------------*/

  /* Reset of all peripherals, Initializes the Flash interface and the Systick. */
  HAL_Init();

  /* Configure the system clock */
  SystemClock_Config();

  /* Initialize all configured peripherals */
  MX_GPIO_Init();
  MX_USART2_UART_Init();
  MX_CAN_Init();
  MX_TIM1_Init();
  MX_TIM3_Init();
  /* USER CODE BEGIN 2 */
  
  HAL_TIM_PWM_Start(&htim3, Left_TIM_CHANNEL);
  HAL_TIM_PWM_Start(&htim3, Middle_TIM_CHANNEL);
  HAL_TIM_PWM_Start(&htim3, Right_TIM_CHANNEL);
  HAL_TIM_PWM_Start(&htim3, Expand_TIM_CHANNEL);

  HAL_TIM_PWM_Start(&htim1, Shaft_TIM_CHANNEL);

  hand_fold();
  HAL_CAN_Start(&hcan);
  if (HAL_CAN_ActivateNotification(&hcan,CAN_IT_RX_FIFO0_MSG_PENDING) != HAL_OK) {
    Error_Handler();
  }
  HAL_GPIO_WritePin(
    STATUS_LED_GPIO_Port,
    STATUS_LED_Pin,
    GPIO_PIN_SET
  );
  /* USER CODE END 2 */

  /* Infinite loop */
  /* USER CODE BEGIN WHILE */
  uint32_t last_heartbeat = HAL_GetTick();
  while (1)
  {
    status_led_update();

    if(HAL_GetTick() - last_heartbeat > HEARTBEAT_MS){
      last_heartbeat = HAL_GetTick();
      stm_can_send(&hcan, &(can_command_data_t){.id = CAN_ID_LOWER_ARM_HEARTBEAT});
    }
    /* USER CODE END WHILE */
    HAL_Delay(LOOP_MS);
    /* USER CODE BEGIN 3 */
  }
  /* USER CODE END 3 */
}

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


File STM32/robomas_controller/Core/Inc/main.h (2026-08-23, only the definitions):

#define B1_Pin GPIO_PIN_13
#define B1_GPIO_Port GPIOC
#define UPPER_ARM_R_LIMIT_Pin GPIO_PIN_2
#define UPPER_ARM_R_LIMIT_GPIO_Port GPIOC
#define UPPER_ARM_DEG_UNDER_LIMIT_Pin GPIO_PIN_3
#define UPPER_ARM_DEG_UNDER_LIMIT_GPIO_Port GPIOC
#define USART_TX_Pin GPIO_PIN_2
#define USART_TX_GPIO_Port GPIOA
#define USART_RX_Pin GPIO_PIN_3
#define USART_RX_GPIO_Port GPIOA
#define Status_LED_Pin GPIO_PIN_5
#define Status_LED_GPIO_Port GPIOA
#define UPPER_ARM_DEG_OVER_LIMIT_Pin GPIO_PIN_4
#define UPPER_ARM_DEG_OVER_LIMIT_GPIO_Port GPIOC
#define LOWER_ARM_R_LIMIT_Pin GPIO_PIN_5
#define LOWER_ARM_R_LIMIT_GPIO_Port GPIOC
#define ROBOMAS_CAN_RX_Pin GPIO_PIN_12
#define ROBOMAS_CAN_RX_GPIO_Port GPIOB
#define ROBOMAS_CAN_TX_Pin GPIO_PIN_13
#define ROBOMAS_CAN_TX_GPIO_Port GPIOB
#define COMMAND_CAN_RX_Pin GPIO_PIN_11
#define COMMAND_CAN_RX_GPIO_Port GPIOA
#define COMMAND_CAN_TX_Pin GPIO_PIN_12
#define COMMAND_CAN_TX_GPIO_Port GPIOA
#define TMS_Pin GPIO_PIN_13
#define TMS_GPIO_Port GPIOA
#define TCK_Pin GPIO_PIN_14
#define TCK_GPIO_Port GPIOA
#define LOWER_ARM_DEG_UNDER_LIMIT_Pin GPIO_PIN_10
#define LOWER_ARM_DEG_UNDER_LIMIT_GPIO_Port GPIOC
#define LOWER_ARM_DEG_OVER_LIMIT_Pin GPIO_PIN_11
#define LOWER_ARM_DEG_OVER_LIMIT_GPIO_Port GPIOC
#define SWO_Pin GPIO_PIN_3
#define SWO_GPIO_Port GPIOB
#define COMMAND_HCAN hcan1
#define ROBOMAS_HCAN hcan2
#define COMMAND_CAN CAN1
#define ROBOMAS_CAN CAN2

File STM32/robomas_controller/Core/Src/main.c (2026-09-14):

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
/* Includes ------------------------------------------------------------------*/
#include "main.h"

/* USER CODE BEGIN Includes */
#include "arm.h"
#include "can_protocol.h"
#include "coordinate.h"
#include "stm32f4xx_hal.h"
#include "stm32f4xx_hal_can.h"
#include "stm32f4xx_hal_gpio.h"
#include "stm_can.h"
#include <math.h>
#include <stdint.h>
#include <string.h>
#include <stdbool.h>
/* USER CODE END Includes */

/* USER CODE BEGIN PTD */
typedef struct
{
    uint16_t angle_raw;

    int32_t total_angle;

    int16_t rpm;
    int16_t current;
    uint8_t temperature;

    uint16_t last_angle; //to calc total_angle

    uint32_t last_update; // 最後に受信した時間 HAL_GetTick()

    bool initialized; //初回ロボマスフィードバックを受けたか
} robomas_feedback_t;

/**
* @param double p;   比例ゲイン 
* @param double i;   積分ゲイン
* @param double d;   微分ゲイン
* @param double mv;  manipulated value 操作量
* @param double sv;  set value 目標値
* @param double it;  integral term 積分項 偏差の総和
* @param double pe;  previous error 直前の偏差
* @param double pv;  process value 制御量 フィードバック
* @param uint32_t last_update;   最後に更新した時間 HAL_GetTick()
**/
typedef struct{
  double p;   //比例ゲイン
  double i;   //積分ゲイン
  double d;   //微分ゲイン
  double mv;  //manipulated value 操作量
  double sv;  //set value 目標値
  double it;  //integral term 積分項 偏差の総和
  double pe;  //previous error 直前の偏差
  double pv;  //process value 制御量 フィードバック
  uint32_t last_update;  // 最後に更新した時間 HAL_GetTick()
}pid_t;

/**
* @param ROBOMAS_INITIAL, // 初回起動時状態．何もトルクを送らない
* @param ROBOMAS_HOMING, // 速度制御によって，リミットスイッチ位置まで回転する
* @param ROBOMAS_IDLE,   // ホーミング終了による他のホーミングを待機
* @param ROBOMAS_READY,  // ユーザが制御可能な状態
* @param ROBOMAS_ERROR,  // フィードバックを受け取れず，制御不能な状態
 */
typedef enum{
  ROBOMAS_INITIAL,  // 初回起動時状態
  ROBOMAS_HOMING,   // 速度制御によって，リミットスイッチ位置まで回転する
  ROBOMAS_IDLE,     // ホーミング終了による他のホーミングを待機
  ROBOMAS_READY,    // ユーザが制御可能な状態
  ROBOMAS_ERROR,    // 制御不能状態
}robomas_state_t;

/**
* @param robomas_feedback_t feedback
* @param pid_t rpm_pid   モーターrpmの制御 
* @param pid_t ang_pid   モーター角(resolution 8192)の制御 
* @param robomas_state_t state     ロボマス制御状態
* @param in32_t total_angle_home 極座標の原点に対応するモーター角(一周あたりの解像度 8192)
* @param int16_t tx_torque     ロボマスへ送るトルク値
* @param double gear_ratio    遊星軸/モーター軸 ギア比
*/
typedef struct{
  robomas_feedback_t feedback;
  pid_t rpm_pid;  //モーターrpmの制御
  pid_t ang_pid;  //モーター角(resolution 8192)の制御
  robomas_state_t state;
  int32_t total_angle_home;//極座標の原点に対応するモーター角(一周あたりの解像度 8192)
  int16_t tx_torque;
  double gear_ratio;  // 遊星軸/モーター軸 ギア比

}robomas_t;

uint32_t upper_homing_start_time;
uint32_t lower_homing_start_time;

//(HOMING -> HOMING_ACK -> ... -> HOMING_DONE -> HOMING_DONE_ACK)
can_sequence_t upper_homing_sequence;
can_sequence_t lower_homing_sequence;

bool upper_homing_done_ack_pending; // HOMING_DONEを送信し，HOMING_DONE_ACK待ちかどうか
bool lower_homing_done_ack_pending;
uint32_t upper_homing_done_sent_time;
uint32_t lower_homing_done_sent_time;
uint8_t upper_homing_done_retry_count;
uint8_t lower_homing_done_retry_count;

// 一度のホーミング試行につき，タイムアウトのCAN_ID_ERROR_CODEは1回しか送らない
bool upper_homing_timeout_notified;
bool lower_homing_timeout_notified;

#define HOMING_DONE_ACK_RETRY_MS 200   //この間隔でHOMING_DONEを再送する
#define HOMING_DONE_ACK_MAX_RETRY 5    //再送を諦めるまでの回数

// Status_LED点滅パターン用
// lowerがREADYでない:+1 upperがREADYでない:+2 (両方でないなら3回点滅) 両方READYなら常時点灯
#define STATUS_LED_BLINK_ON_MS   150
#define STATUS_LED_BLINK_OFF_MS  150
#define STATUS_LED_BLINK_PAUSE_MS 700
uint8_t status_led_blink_index; //現在の点滅サイクルで何回点滅したか
bool status_led_on;
uint32_t status_led_phase_start;
/* USER CODE END PTD */

/* USER CODE BEGIN PD */
#define LOOP_MS 2
#define ROBOMAS_FEEDBACK_TIMEOUT_MS 100

#define ROBOMAS_NUM 4

#define ROBOMAS_MAX_TORQUE 16384 //ロボマスに送れる最大電流値
#define ROBOMAS_M3_GEAR_RATIO (3591.0 / 187.0)//M3508
#define ROBOMAS_M2_GEAR_RATIO 36              //M2006
#define ROBOMAS_ANGLE_RESOLUTION 8192 //0〜8191

// ROBOT_TEAM(出場チーム 青/赤)はcommon/arm/inc/arm.hで定義される。
// ESP32/STM32の全ファームウェアで共有する値なので，このファイルでは再定義しない。

//上下でロボマスの取り付け向きが逆なため，R軸と同様にDEG軸も上下で別定数にして符号を反転する
//(この符号は配線・機構で決まる固定値で，チームによっては変わらない)
#define LOWER_ARM_DEG_ROBOMAS_DIRECTION 1 //上から見て半時計回りが正でモーターは右ねじを正とするとき
#define UPPER_ARM_DEG_ROBOMAS_DIRECTION 1
#define LOWER_ARM_R_ROBOMAS_DIRECTION 1 //アームが伸びる方向が正でモーター右ねじ正
#define UPPER_ARM_R_ROBOMAS_DIRECTION -1


//ToDo: pullupしているので，導通したらRESET，していないならSETになる．リミットスイッチの接続によって変える．
//      リミットスイッチ：COM NO NC の三つのコネクタがあり，COMは常に接続されている．NOはスイッチを押すと導通，NCはスイッチを離すと導通．
#define LOWER_ARM_DEG_UNDER_LIMIT_ON (HAL_GPIO_ReadPin(LOWER_ARM_DEG_UNDER_LIMIT_GPIO_Port, LOWER_ARM_DEG_UNDER_LIMIT_Pin) == GPIO_PIN_RESET)
#define LOWER_ARM_DEG_UNDER_LIMIT_OFF !LOWER_ARM_DEG_UNDER_LIMIT_ON
#define LOWER_ARM_DEG_OVER_LIMIT_ON (HAL_GPIO_ReadPin(LOWER_ARM_DEG_OVER_LIMIT_GPIO_Port, LOWER_ARM_DEG_OVER_LIMIT_Pin) == GPIO_PIN_RESET)

#define LOWER_ARM_R_LIMIT_ON (HAL_GPIO_ReadPin(LOWER_ARM_R_LIMIT_GPIO_Port, LOWER_ARM_R_LIMIT_Pin) == GPIO_PIN_RESET)
#define LOWER_ARM_R_LIMIT_OFF !LOWER_ARM_R_LIMIT_ON

#define UPPER_ARM_DEG_UNDER_LIMIT_ON (HAL_GPIO_ReadPin(UPPER_ARM_DEG_UNDER_LIMIT_GPIO_Port, UPPER_ARM_DEG_UNDER_LIMIT_Pin) == GPIO_PIN_RESET)
#define UPPER_ARM_DEG_UNDER_LIMIT_OFF !UPPER_ARM_DEG_UNDER_LIMIT_ON
#define UPPER_ARM_DEG_OVER_LIMIT_ON (HAL_GPIO_ReadPin(UPPER_ARM_DEG_OVER_LIMIT_GPIO_Port, UPPER_ARM_DEG_OVER_LIMIT_Pin) == GPIO_PIN_RESET)

#define UPPER_ARM_R_LIMIT_ON (HAL_GPIO_ReadPin(UPPER_ARM_R_LIMIT_GPIO_Port, UPPER_ARM_R_LIMIT_Pin) == GPIO_PIN_RESET)
#define UPPER_ARM_R_LIMIT_OFF !UPPER_ARM_R_LIMIT_ON

// 赤/青チームはフィールドが鏡合わせのため整理機構を左右逆側に付け替える必要があり，
// それに合わせてDEG軸(偏角)をどちら側の可動端(リミットスイッチ)を原点として
// ホーミングするかを切り替える(LOWER/UPPER_ARM_DEG_HOME_DEGはcommon/arm/inc/arm.h参照)。
// 赤チーム: 可動域下限(*_DEG_UNDER_LIMIT，整理機構は左)へ向けてホーミングする(従来通り)。
// 青チーム: 可動域上限(*_DEG_OVER_LIMIT，整理機構は右)へ向けてホーミングする。
// ホーミング回転方向は，原点にする側へ実際に向かうよう符号(*_DEG_HOMING_DIRECTION_SIGN)を
// 反転させる。*_DEG_ROBOMAS_DIRECTION(配線で決まる固定値)自体は変えない。
#if ROBOT_TEAM == ROBOT_TEAM_BLUE
#define LOWER_ARM_DEG_HOMING_LIMIT_ON LOWER_ARM_DEG_OVER_LIMIT_ON
#define UPPER_ARM_DEG_HOMING_LIMIT_ON UPPER_ARM_DEG_OVER_LIMIT_ON
#define LOWER_ARM_DEG_HOMING_DIRECTION_SIGN 1
#define UPPER_ARM_DEG_HOMING_DIRECTION_SIGN 1
#else
#define LOWER_ARM_DEG_HOMING_LIMIT_ON LOWER_ARM_DEG_UNDER_LIMIT_ON
#define UPPER_ARM_DEG_HOMING_LIMIT_ON UPPER_ARM_DEG_UNDER_LIMIT_ON
#define LOWER_ARM_DEG_HOMING_DIRECTION_SIGN (-1)
#define UPPER_ARM_DEG_HOMING_DIRECTION_SIGN (-1)
#endif

/* USER CODE END PD */

CAN_HandleTypeDef hcan1;
CAN_HandleTypeDef hcan2;

UART_HandleTypeDef huart2;

/* USER CODE BEGIN PV */
direct_t coordinate[ARM_NUM] = {LOWER_ARM_HOME_COORDINATE, UPPER_ARM_HOME_COORDINATE};
#define coordinate_lower coordinate[0]
#define coordinate_upper coordinate[1]
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

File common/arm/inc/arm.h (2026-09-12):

#define ARM_NUM 2
#define UPPER_ARM_R_RANGE 665.0   //ToDo: 上側アームのアーム長可動域(mm)
#define UPPER_ARM_R_MIN 415.0     //ToDo: アーム長を一番短くしたときのR(mm)を測る
#define UPPER_ARM_DEG_RANGE 180.0 //偏角の可動域(degree)
#define UPPER_ARM_DEG_MIN 180.0     //偏角の下限。上のアームはハンドの取り付け側が下のアームと逆(180度回転してついている)ため，下のアームと違い0度にならない

#define UPPER_ARM_Z_SERVO_GEAR_DIAMETER 80  //mm
#define UPPER_ARM_Z_MIN 0.0                 //Zの下限(mm)
#define UPPER_ARM_Z_RANGE 174                //Zの可動域(mm)

#define LOWER_ARM_R_RANGE 834.0   //ToDo: 下側アームのアーム長可動域(mm)
#define LOWER_ARM_R_MIN 342.0     //ToDo: アーム長を一番短くしたときのR(mm)を測る
#define LOWER_ARM_DEG_RANGE 180.0 //偏角の可動域(degree)
#define LOWER_ARM_DEG_MIN 0.0     //偏角の下限


#define R_ROBOMAS_DIAMETER 30.0 //アーム長ロボマスにつくギアの直径(mm)

#define POLAR_RATIO (4.0/1.0) //アーム軸/モーター軸　直径比

// 出場チーム(青/赤)。競技開始前に決定した後は変更しない。
// 緊急停止スイッチが押されるとESP32/STM32の各基板は再起動するため，実行時にトグルする
// 方式では状態を保持できない。そのため，チームに応じてこの値を書き換えてビルド・
// 書き込みすることで固定する。
// このarm.hを使う全ファームウェア(ESP32 Main Controller，STM32の
// robomas_controller/lower_arm_servo/upper_arm_servo)で必ず同じ値にすること。
// (値がずれると，DEG軸のホーミングで検出するリミットスイッチと回転方向が
//  ファームウェア間で食い違い，可動域の反対側の固定端に衝突する恐れがある。)
#define ROBOT_TEAM_BLUE 0
#define ROBOT_TEAM_RED  1
#define ROBOT_TEAM ROBOT_TEAM_RED  //出場チームに応じて書き換えてビルドする

// 赤/青チームは，フィールドが鏡合わせのため整理機構を左右逆側に取り付け直す必要があり，
// それに合わせて上下アームとも「DEG軸(偏角)のどちら側の可動端をホーミング原点にするか」を
// 切り替える(実際に機体やロボマスの配線が反転するわけではない)。
// 赤チームは可動域下限(*_DEG_UNDER_LIMIT，整理機構は左側)，
// 青チームは可動域上限(*_DEG_OVER_LIMIT，整理機構は右側)を原点にする。
// LOWER/UPPER_ARM_DEG_HOME_DEGはこの原点に対応する偏角(度)。DEG_MIN側を原点にする場合は
// そのままDEG_MIN，DEG_MIN+RANGE側(可動域の反対側の端)を原点にする場合はDEG_MIN+RANGEを
// 使う(360度になっても0度に正規化しない。coordinate.hのto_polar()は[0,2π)にラップして
// 返すため，そのまま比較・減算する側で360度をまたぐ場合の連続性を考慮する必要がある。
// STM32/robomas_controllerのpolar_deg_unwrapped()，STM32/upper_arm_servoの
// 偏角正規化処理を参照)。
#if ROBOT_TEAM == ROBOT_TEAM_BLUE
#define LOWER_ARM_DEG_HOME_DEG (LOWER_ARM_DEG_MIN + LOWER_ARM_DEG_RANGE)
#define UPPER_ARM_DEG_HOME_DEG (UPPER_ARM_DEG_MIN + UPPER_ARM_DEG_RANGE)
#else
#define LOWER_ARM_DEG_HOME_DEG (LOWER_ARM_DEG_MIN)
#define UPPER_ARM_DEG_HOME_DEG (UPPER_ARM_DEG_MIN)
#endif

// ホーミング原点(LOWER/UPPER_ARM_DEG_HOME_DEG)に対応する座標。
#if ROBOT_TEAM == ROBOT_TEAM_BLUE
#define LOWER_ARM_HOME_COORDINATE {\
  .x = -LOWER_ARM_R_MIN,\
  .y = 0,\
}
#define UPPER_ARM_HOME_COORDINATE {\
  .x = UPPER_ARM_R_MIN,\
  .y = 0,\
}
#else
#define LOWER_ARM_HOME_COORDINATE {\
  .x = LOWER_ARM_R_MIN,\
  .y = 0,\
}
#define UPPER_ARM_HOME_COORDINATE {\
  .x = -UPPER_ARM_R_MIN,\
  .y = 0,\
}
#endif

//HOMING
#define HOMING_UPPER_ARM_TIMEOUT_MS 10000
#define HOMING_LOWER_ARM_TIMEOUT_MS 10000

#define HOMING_TIMEOUT_MARGIN_RATE 0.6

//                                                                  rotation   per  second
#define HOMING_UPPER_DEG_RPM  ((UPPER_ARM_DEG_RANGE / 360 * POLAR_RATIO)        /   (HOMING_UPPER_ARM_TIMEOUT_MS/1000.0/60.0 * HOMING_TIMEOUT_MARGIN_RATE))
#define HOMING_LOWER_DEG_RPM  ((LOWER_ARM_DEG_RANGE / 360 * POLAR_RATIO)        /   (HOMING_LOWER_ARM_TIMEOUT_MS/1000.0/60.0 * HOMING_TIMEOUT_MARGIN_RATE))
#define HOMING_UPPER_R_RPM    ((UPPER_ARM_R_RANGE/(R_ROBOMAS_DIAMETER * M_PI))  /   (HOMING_UPPER_ARM_TIMEOUT_MS/1000.0/60.0 * HOMING_TIMEOUT_MARGIN_RATE))
#define HOMING_LOWER_R_RPM    ((LOWER_ARM_R_RANGE/(R_ROBOMAS_DIAMETER * M_PI))  /   (HOMING_LOWER_ARM_TIMEOUT_MS/1000.0/60.0 * HOMING_TIMEOUT_MARGIN_RATE))

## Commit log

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2026-07-11 add Kicad
    [servo.kicad_pcb, servo.kicad_sch]
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2026-08-08 servo回路作成＆PCB用
    [bom.csv, designators.csv, positions.csv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]
2026-08-09 最新回路基盤 動作表示用LEDもつけた
    [bom.csv, designators.csv, positions.csv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]
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2026-08-12 ESP32のシンボルとフットプリント作成
    [ESP.kicad_pcb, ESP.kicad_sch]
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2026-08-14 STMライブウォッチ機能により，正しく受信できたことを確認． iocの設定を修正．
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2026-08-15 lower_arm_servo Kicad 完成
    [STM32F303K8_lower_arm_servo.kicad_pcb, STM32F303K8_lower_arm_servo.kicad_sch]
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2026-08-17 stm F4追加
    [STM32F446RE_robomas_controller.kicad_pcb, STM32F446RE_robomas_controller.kicad_sch]
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2026-08-19 robomas用の回路完成
    [STM32F446RE_robomas_controller.kicad_pcb, STM32F446RE_robomas_controller.kicad_sch]
2026-08-21 回路完成
    [ESP.kicad_pcb, ESP.kicad_sch, STM32F303K8_lower_arm_servo.kicad_pcb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]
2026-08-21 回路3Dデータをstepとしてエクスポート
    [.step]
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2026-08-27 pid resetは時間も更新するので，ERRORからすぐ抜けられるのを修正
2026-08-27 error_codeを実装
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2026-08-29 STM32ファームウェアのビルドCIを追加
    GitHub Actionsで、STM32の3プロジェクト(lower_arm_servo /
    upper_arm_servo / robomas_controller)をpush・PRごとに
    arm-none-eabi-gcc + CMake(Releaseプリセット)でビルドし、
    コンパイルエラーを検知できるようにする。ローカルで3プロジェクト
    とも実際にビルドが通ることを確認済み。
2026-08-29 アームL/Rボタンの実装を修正: ハンドの向きを90度回転するように変更
    前回の実装は「可動域」をアーム軸のx,y座標の可動域と誤解し、ESP32側
    でx,y移動範囲を制限する形にしていたが、正しくは「アーム先端のハンド
    部分の角度」を指していた。STM32側でx,y座標からアーム軸の回転角を
    計算し、アーム軸が回転してもハンドの向きが変わらないよう補正して
    いるシャフトサーボがこれにあたる。
    修正内容:
    - common/can_protocol: lower_arm_tにshaft_rotateビットを追加
    (CAN上のデータサイズは変わらない、既存hand byteの空きビット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
    [main.c]
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2026-08-30 assemble_servo: 角度指令のスケーリングバグを修正
    - assemble_deg(uint8_t)を270で整数除算していたため常に0になり，
    サーボがCAN指令を受けても動かない不具合を修正
    - 実際の可動域である ASSEMBLE_DEG_RANGE(90度) を分母に使うよう修正
    - 浮動小数点で計算するようキャストを追加
    - 範囲外の入力に対する安全のためクランプを追加
    [main.c]
2026-08-30 assemble_servo: 角度指令のスケーリングを1:1対応に修正
    入力角度をASSEMBLE_DEG_RANGE(機構の可動域=90度)で正規化していたが，
    実際には入力値がそのままサーボの角度(0-270度)に1:1対応するとのフィードバックを受け，
    分母をサーボの角度レンジ(SERVO_DEG_RANGE=270度)に修正．
    ASSEMBLE_DEG_RANGEは機構の可動域へのクランプ用途として引き続き使用．
    [main.c]
2026-08-30 assemble_servo: STATUS_LEDで正常/異常を表示するように
    - 正常動作中は点灯
    - 以下を検知したら点滅(ラッチ):
    - CANバスエラー(バスオフ/エラーパッシブ/エラーワーニング)をメインループで監視
    - Error_Handler()に入った場合(初期化失敗などで動作不能な状態)
    割り込み無効化後もソフトウェアループでLEDを点滅させる
    [main.c]
2026-08-30 can: CANエラーハンドリングの復帰処理を修正
    - twai_get_status_info()失敗時にstatus_infoが更新されないまま
    古い/未初期化のsで分岐していた問題を修正し、次ループで状態を
    取り直すようにした
    - 再インストール失敗時にcan_error_handling_taskを削除して
    以後の自動復帰を諦めていた挙動をやめ、リトライを継続するように変更
    (delete後の到達不能コードも解消)
    - 再インストール時にDEFAULT_TX_GPIO/DEFAULT_RX_GPIO固定だったのを
    can_init_and_start()に渡された実際のGPIOを保持して使うよう修正
    - twai_initiate_recovery()/twai_start()の戻り値を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
    [can.c]
2026-08-30 Add ESP32 (ESP32/controller) build CI workflow
    STM32のCI(.github/workflows/stm32-build.yml)に合わせて、ESP-IDFプロジェクト
    ESP32/controllerをビルドするGitHub Actionsワークフローを追加。
    - espressif/idf:v5.5.4 コンテナ上でビルド(README記載のESP-IDFバージョン、
    .devcontainer/Dockerfileと同じベースイメージ)
    - components/procon が依存するBluepad32/BTstack(リポジトリに同梱されず
    ~/.espressif/bluepad32を参照する外部依存)をactions/cacheでキャッシュ
    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
2026-08-31 READMEの内容を実装に合わせて修正
    実コードとREADMEの差分を洗い出して修正:
    - common/can_protocol: lower_arm_t.hand に shaft_rotate(bit4)が
    抜けていたので追加
    - STM32/lower_arm_servo: CAN受信ハンドラが未実装時のstubのまま
    だったので実際の実装(ハンドPWM制御・Shaft角度計算・Heartbeat
    送信)に更新
    - STM32/robomas_controller: 冒頭のピン表がラベルなしの
    GPIO_Input_1〜6等になっていたので実際の信号名に置き換え
    - STM32/upper_arm_servo: CANハンドラが未実装であることを明記
    - STM32/assemble_servo: READMEが存在しなかったので新規作成
    - ESP32/controller: lowe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
2026-09-02 upper_arm: Shaft/Zの可動域クランプとエラー時LED点滅を追加
    レビュー指摘の対応:
    - STM32側: Shaft/Zのパルス幅をSERVO_0~SERVO_270にクランプ。
    クランプが発生した場合はSTATUS_LEDを高速点滅させる(通常時は低速点滅の
    ハートビート)。ホーミング時のZ位置は現状維持のまま変更なし。
    - ESP32側: upper_arm.zの更新をint32_tで計算してから可動域
    (UPPER_ARM_Z_MIN~+UPPER_ARM_Z_RANGE)にクランプするよう変更。
    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
2026-09-02 robomas_controller: 起動時の全ロボマス待ちブロッキングを解消
    main()冒頭でROBOMAS_NUM(4台)すべてのフィードバック初期化を待つ
    while文が、一部のロボマスターしか接続していない構成(下アームの
    2台のみ接続しての動作確認など)ではメインループに一切到達できず、
    接続済みのロボマスターについても制御・Heartbeat送信・Status_LED
    表示が何も行われなくなる問題があった。
    未接続の軸はrobomas_update()のROBOMAS_FEEDBACK_TIMEOUT_MSタイム
    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
2026-09-07 STM32用Dev Containerを追加し、ESP32側のマウント漏れを修正
    ESP-IDF拡張とSTM32系拡張(clangd)が同じVS Codeウィンドウで
    干渉する問題に対し、用途別にDev Container(Docker)を用意して
    必要な拡張だけをコンテナ内にインストールする構成にした。
    - STM32/.devcontainer を新規追加。lower_arm_servo/upper_arm_servo/
    robomas_controller/assemble_servoの4プロジェクト共通で使う。
    ツールチェインは.github/workflows/stm32-build.ymlと同じ
    (gcc-arm-none-eabi + ninja-build + cmake)。既存の.clangdに
    合わせてclangd拡張を入れ、cpptoolsやSTM32公式拡張は入れない。
    - ESP32/controller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
2026-09-07 ESP32のDev ContainerにBluepad32セットアップを統合
    components/procon が依存するBluepad32/BTstack(~/.espressif/bluepad32)は
    これまで.github/workflows/esp32-build.ymlにしか取得手順がなく、
    Dev Container単体ではidf.py buildが失敗する状態だった。
    - postCreateCommandからsetup-bluepad32.shを実行し、CIと同じ手順
    (clone + integrate_btstack.py)でコンテナ作成時に自動取得するようにした
    - ~/.espressif をDockerボリュームにマウントし、コンテナ再作成のたびに
    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
2026-09-07 ESP32 Dev ContainerのESP-IDFバージョンをv5.5.4に固定
    Dockerfileの ARG DOCKER_TAG のデフォルトが "latest" のままだったため、
    Docker Hub側のespressif/idfイメージが新しいメジャーバージョン(v6系)に
    切り替わるとDev Containerだけビルドが壊れる状態だった
    (CIはespressif/idf:v5.5.4に固定済み、READMEもv5.5.4前提)。
    Bluepad32は現時点でESP-IDF v6系のサポートを明言していないため、
    "latest"追従ではなくCI/READMEと同じv5.5.4に固定した。
    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
2026-09-07 setup-bluepad32.sh: 不完全なcloneを検知して再取得するよう修正
    EXTRA_COMPONENT_DIRSに指定されたbluepad32/src/componentsが存在せず
    CMake configureが失敗する報告があった。src/componentsはBluepad32本体の
    通常のディレクトリなので、これが無いのはpostCreateCommandによるclone
    が(ネットワークエラー等で)完了していないことを意味する。
    従来は".git"の存在だけを見て「clone済み」と判定していたため、
    ~/.espressif をキャッシュする名前付きボリュームに不完全な状態が
    残っていると再cloneされずスキップされていた。src/componentsの存在も
    チェッ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
2026-09-07 Fix ESP32 controller build warnings
    - Enable CONFIG_GPTIMER_SUPPRESS_DEPRECATE_WARN to silence the
    legacy timer group driver deprecation #warning pulled in by
    bluepad32's uni_mouse_quadrature.c (vendored dependency, not
    something we can edit directly).
    - Rewrite the multi-line format string in mypad_dump() using
    adjacent string literal concatenation instead of backslash line
    continuation. The old continuation left a stray backslash right
    before each continued line's leading space, which GCC parsed as
    an invalid "\ " escape sequence (reported as "\040").
    Claude-Session: https://claude.ai/code/session_01LtYN83Uxm2Xv9onKpNRf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
2026-09-09 arm_commandの説明修正
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2026-09-09 180度回転を上側ではなく下側シャフトに修正し、L/Rを微調整・ZL/ZRを180度切替に変更
    前回の変更は上側アームのシャフトに180度回転を実装していたが、正しくは下側
    アームのシャフトだったため、upper_arm_tへの変更(shaft_rotateフラグ、DLC7化)を
    全て取り消し、upper_arm_move()を元の3引数シグネチャに戻した。
    下側アーム(lower_arm)側を以下のように変更:
    - 既存のshaft_rotateトグル(90度)を180度に変更
    - L/Rボタンは押しっぱなしでシャフト角度を微調整(±1度/ループ、
    ±LOWER_ARM_SHAFT_FINE_MAX_DEG=15度でクランプ)する専用ボタンに変更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
    [main.c]
2026-09-09 下側シャフトの180度回転をチームごとの可動範囲内でのみ許可するよう変更
    競技開始前に決定するチーム(青/赤)に応じて，shaft_rotate(180度回転)を
    許可するアーム偏角の範囲が異なる:
    - 青チーム: アーム角0~90度の範囲でのみ180度回転がサーボの可動域(0~270度)に
    収まる(90~180度側では可動域の上限に達する)
    - 赤チーム: 逆にアーム角90~180度の範囲でのみ収まる
    STM32(lower_arm_servo)にROBOT_TEAM(コンパイル時定数)を追加し，出場チームに
    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
2026-09-12 上アームの偏角回転方向を修正
    上下のロボマスは取り付け向きが逆(R軸は既にLOWER/UPPER別定数で対応済み)
    なのに，偏角(DEG)方向はARM_DEG_ROBOMAS_DIRECTIONが上下共通のままだった．
    これによりESP32側で下入力→θ減少という同じ計算結果でも，実機では上アーム
    だけ物理的な回転方向が反転し，下入力で意図と逆(奥)に動いていた．
    R軸と同様にLOWER_ARM_DEG_ROBOMAS_DIRECTION/UPPER_ARM_DEG_ROBOMAS_DIRECTION
    に分割し，上アームのみ符号を反転する．
    Claude-Session: https://claude.ai/code/session_01PT9XJqf85i2zo1vw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
    [main.c]
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2026-09-12 上のアームの偏角を下のアームと同じ座標系で正しく扱うよう修正
    上のアームはハンドの取り付け側が下のアームと逆(180度回転してついている)ため，
    偏角(x,y座標系のtheta)の可動域はUPPER_ARM_DEG_MIN~MIN+RANGE(180~360度)になる。
    しかし以下の3箇所が下のアーム(可動域0~180度)と同じ計算式のままだったため，
    上のアームだけ挙動がおかしくなっていた。
    - common/arm/inc/arm.h: UPPER_ARM_HOME_COORDINATEがtheta=0の座標になっており，
    可動域(180~360度)の外だった。ホーミング直後にESP32側の可動域チェックに
    常に弾かれ，ジョイスティ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
    [arm.h, main.c]
2026-09-12 DEG軸のホーミング方向をROBOT_TEAMで切り替えられるようにする
    赤/青チームは整理機構を逆側に付け替えるため，機体が互いに向かい合わせの
    鏡合わせ構造になる。鏡映は回転の向き(ハンドル性)を反転させるため，
    上下アームどちらもDEG軸(偏角)のロボマス回転方向は本来チームで反転する必要が
    あったが，従来は固定値だった。
    STM32/lower_arm_servoに既にあるROBOT_TEAM(RED/BLUE)マクロと同じ方式を
    STM32/robomas_controllerにも導入し，LOWER_ARM_DEG_ROBOMAS_DIRECTION /
    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
2026-09-12 上アームのShaft(ハンド向き)にもZL/ZRで180度回転を追加
    下アームと同様，ZL/ZRのPRESSEDエッジでupper_arm.shaft_rotateをトグルし，
    ホーミング原点からの相対偏角(0~180度)にM_PI(180度)を加算してからサーボの
    パルス幅に変換するようにした。270度サーボのうち普段使うのは可動範囲分の
    180度だけなので，相対偏角が90度を超える場合は反対側まで回転しきれないが，
    その場合は新たな許容範囲チェックを設けず，既存のclamp_servo_pulse()による
    SERVO_270へのクランプにまかせて「回転を適用しない」ことにした(そのたびに
    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
2026-09-12 Revert "上アームのShaft(ハンド向き)にもZL/ZRで180度回転を追加"
    This reverts commit c76520f96eff0474893f97724c3bd7d6840cca9d.
    [main.c]
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2026-09-12 上アームのハンド向きをL/Rで微調整、ZL/ZRで90度回転できるようにする
    下アーム(shaft_fine/shaft_rotate)と同じ仕組みを上アームにも追加した。
    - common/can_protocol: upper_arm_tにshaft_fine(int8_t)とshaft_rotate(1bit)
    を追加し、CAN_ID_UPPER_ARM_COMMANDのDLCを6→8に変更
    - ESP32: upper_arm_move()にd_shaft_fine/shaft_rotate_toggle引数を追加し、
    main_task()でL/RとZL/ZRの入力を渡すよう変更。ホーミング完了時にリセット
    - STM32/upper_arm_servo: shaft_rotate=1で90度回転(赤/青チームで±90度)、
    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
2026-09-12 上アームShaftサーボの回転方向反転を修正
    shaft_deg_from_home()はチームのホーミング原点との差の絶対値(fabs)を
    とっていたため，赤/青チームでアーム回転に対するShaftの回転方向が逆に
    なっていた。
    アームの可動域中央(真下向き，270度)をShaftの使用域中央(135度)に
    合わせるだけの単純な線形対応(shaft_deg_from_arm_deg())に変更し，
    fabsによる折り返しをなくして両チームで回転方向を揃えた。
    これにより，
    - アームが真下向き(270度)のとき，チームによらずShaftはSERVO_135相当になる
    - 青チームのホーミング原点(ホーム位置)で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
    [main.c]
2026-09-12 下アームShaftサーボも真上向きでSERVO_135になるよう中央合わせ
    上アームと同様に，アーム可動域の中央(下アームは真上向き，偏角90度)を
    Shaftの使用域中央(135度)に合わせるshaft_deg_from_arm_deg()を追加し，
    座標から直接theta(0~180度)を使っていた計算をこれに置き換えた。
    - アームが真上向き(偏角90度)のとき，Shaftはチームによらず
    SERVO_135相当になる
    - 青チームのホーミング原点ではSERVO_225相当，赤チームのホーミング原点
    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
2026-09-12 整理機構のサーボ操作をPLUS/MINUSとX/Yで切り替え
    - PLUS: 90度へ即座に切り替え
    - MINUS: 0度へ即座に切り替え
    - X押しっぱなし: 90度側へ徐々に移動(ASSEMBLE_DEG_STEP/ループ)
    - Y押しっぱなし: 0度側へ徐々に移動(ASSEMBLE_DEG_STEP/ループ)
    現在の指令角度をassemble_degとして保持し，毎ループCAN送信するように変更。
    dump_taskにも現在角度のログを追加。
    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
2026-09-14 docs: 全READMEの内容を実装と相互に整合させる
    複数のREADMEがコードや他のREADMEと食い違っていたため，実装を正として揃えた．
    仕様の食い違い:
    - can_protocol: CAN ID一覧のDLCを実装(can_protocol.h)に合わせる
    (UPPER_ARM_COMMAND 7->8, LOWER_ARM_COMMAND 5->6)．C言語表現の章の
    「lower_arm_tは5 byte」も6 byteに修正．
    - shaft_fineの有効範囲を±15から実際の±45(*_SHAFT_FINE_MAX_DEG)に修正．
    - CANビットレートを1Mbpsに統一(ESP32 READMEのみ500kbpsと記載されていた)．
    - hand_state_tのサーボ角度はハンドの取り付け向きで変わるため，プロトコル側では
    規定せ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
2026-09-14 docs: ソースコードのコメントを実装に合わせる
    READMEの整合作業で見つかった，コメントと実装のずれを修正した．動作の変更はない．
    - can_protocol.h: hand_state_tのコメントがサーボ0/45/180度と書いていたが，
    実際の角度はハンドの取り付け向きによって変わる(lower_arm_servoの
    hand_state_to_pulse()がLeftとMiddle/Rightで別のパルス幅を返す)ため，
    プロトコル側では角度を規定せず受信側を参照する旨に変更．
    - upper_arm_servo: status_led_update()のコメントが存在しない
    STATUS_LED_BLINK_MSに言及していたが，実際は正常時は点灯したまま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
    [main.c]
2026-09-14 Update actuator list and motor connection details
    Removed Robomaster M2006 from actuator list and updated motor connection information.
2026-09-15 Revise README.md for power board components
    Updated component list for power board and other sections.

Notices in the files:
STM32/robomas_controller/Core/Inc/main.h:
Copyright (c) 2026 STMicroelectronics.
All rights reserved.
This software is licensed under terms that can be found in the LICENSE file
